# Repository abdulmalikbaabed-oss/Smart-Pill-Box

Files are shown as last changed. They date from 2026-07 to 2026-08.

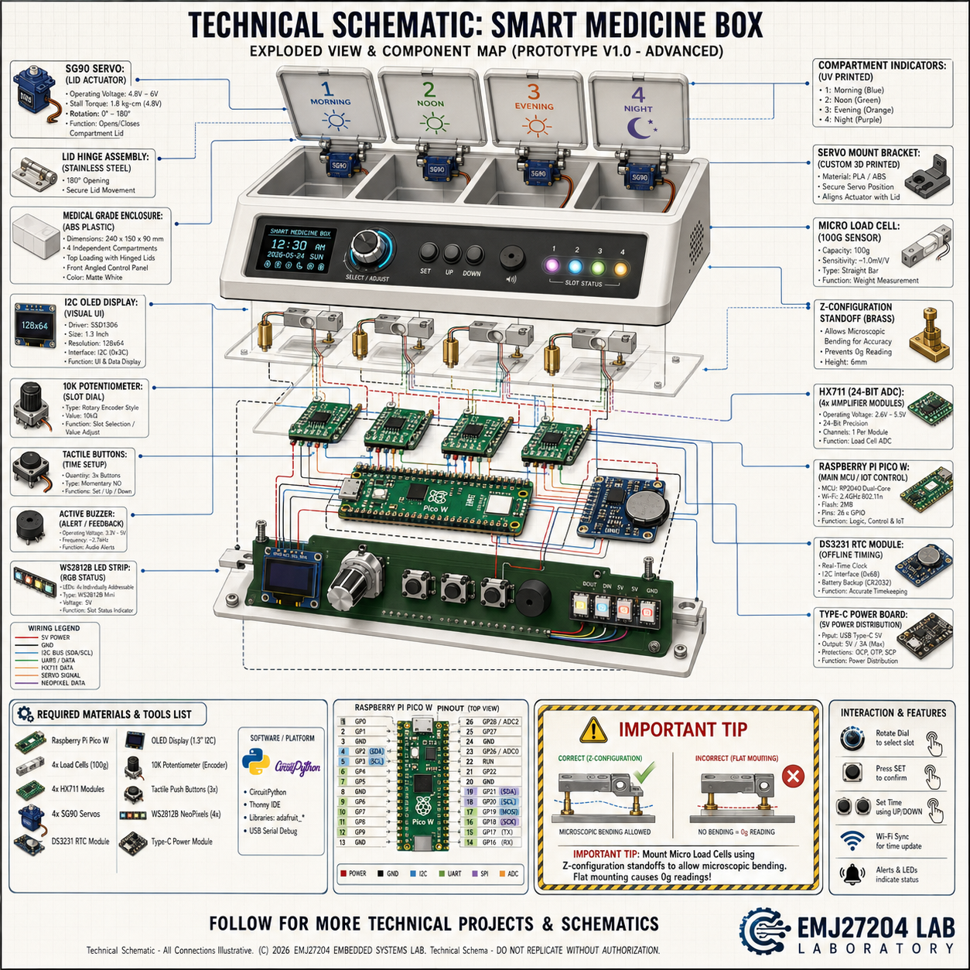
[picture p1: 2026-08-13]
04_Hardware_Schematics/Box design+3D Printing/ALBOX.png

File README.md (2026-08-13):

# 🌟 Comprehensive Operation Guide: Smart Medicine Box Project 🌟

Welcome to the "Smart Medicine Box" project. This embedded system is built on the pyRTOS architecture and object-oriented programming (OOP) using a Raspberry Pi Pico W. The system aims to monitor the elderly's adherence to their medication regimen through weight sensors, synchronize data with the cloud (Blynk IoT), and record it locally in an Excel file.

Follow these engineering steps precisely to build and run the system from scratch:

---

## 🛒 Step 1: Hardware Procurement
Before starting anything, you must ensure you have the necessary electronic components:

1. Go to the `04_Hardware_Schematics` folder and open the **Component List (Excel/PDF)** file.

2. Check the required components (e.g., Raspberry Pi Pico W, HX711, Load Cells, OLED, SG90 Servos, etc.).

3. If any components are missing, order and purchase them online or from local electronics stores before proceeding to the next steps.

---

## 💻 Step Two: Software Transfer
We will now format the system unit (Raspberry Pi Pico W):
1. Connect the Pico W board to your computer until it appears as a storage drive named `CIRCUITPY`.

2. **Transfer Libraries:** Open the `02_Libraries` folder and copy the entire `lib` folder, then paste it into the `CIRCUITPY` directory.

3. **Moving Code:** Open the `01_Source_Code` folder and copy all the Python files (`code.py`, `compartment.py`, `smart_scale.py`, `scale_config.py`, `secrets.py`) and paste them into the root directory of Pico (next to the `lib` folder).

---

## ⚙️ Step Three: Code Customization
You need to modify some data in the code to suit your network and device:

1. **Network and Cloud Settings:** - Open the **`secrets.py`** file located inside Pico.

- Change the following data as needed:

- Line 2: `"ssid": "Your Wi-Fi network name"`

- Line 3: `"password": "Your Wi-Fi password"`

- Line 4: `"blynk_token": "Your Blink token code"`

- Save the file.

2. **Connection Port Settings (for Excel Logging):**

- Open the **`logger.py`** file located in the `03_PC_Data_Logger` folder on your laptop.

- Go to **approximately line 9**: `COM_PORT = 'COM16'`

- Change `'COM16'` to the actual port number that the Pico is connecting to on your computer (you can find this using Thonny or Device Manager).

- Save the file.

---

## 🔌 Step Four: Building the Electronic Circuit (Hardware Wiring)
1. Refer to the components list (Excel) to familiarize yourself with the function of each component and its ports.

2. Open the main electronic schematic **`schematic_circuit.pdf`** located in the `04_Hardware_Schematics` folder.

3. Connect the wires precisely as shown in the schematic (ensure that the 5V power supply is separate from the 3.3V supply to avoid damaging the microcontroller).

---

## ☁️ Step Five: Setting Up the Mobile Application (Blynk IoT Setup)
To create the mobile interface and connect push notifications:

1. Open the `Blynk` folder located inside `04_Hardware_Schematics`.

2. Open the text file **`Blynk_Documentation_and_Event_Setup.txt`**.

3. This file contains a comprehensive engineering guide. Follow the instructions precisely to create Virtual Pins (V0-V15), select the appropriate widgets, and enable notification events to be sent to the patient's phone.

---

## ⚖️ Step Six: Mechanical Assembly and System Operation
1. **Physical Assembly:** Due to the sensitivity of the Load Cell, it must be mounted so that it does not touch the walls of the box. **Refer to the attached illustrations in the project archive** for the correct physical arrangement of the scale and mechanical components.

2. **Starting Data Logging:**

- Ensure that the Thunny program is completely closed to prevent it from blocking the connection.

- Navigate to the `03_PC_Data_Logger` folder.

- Open the Command Prompt (CMD) and run the code using the command: `python logger.py`

- The system will now automatically track and record each pill in the `medication_log.csv` file.

🎉 **Congratulations!** Your system is now ready and operating with high professionalism.

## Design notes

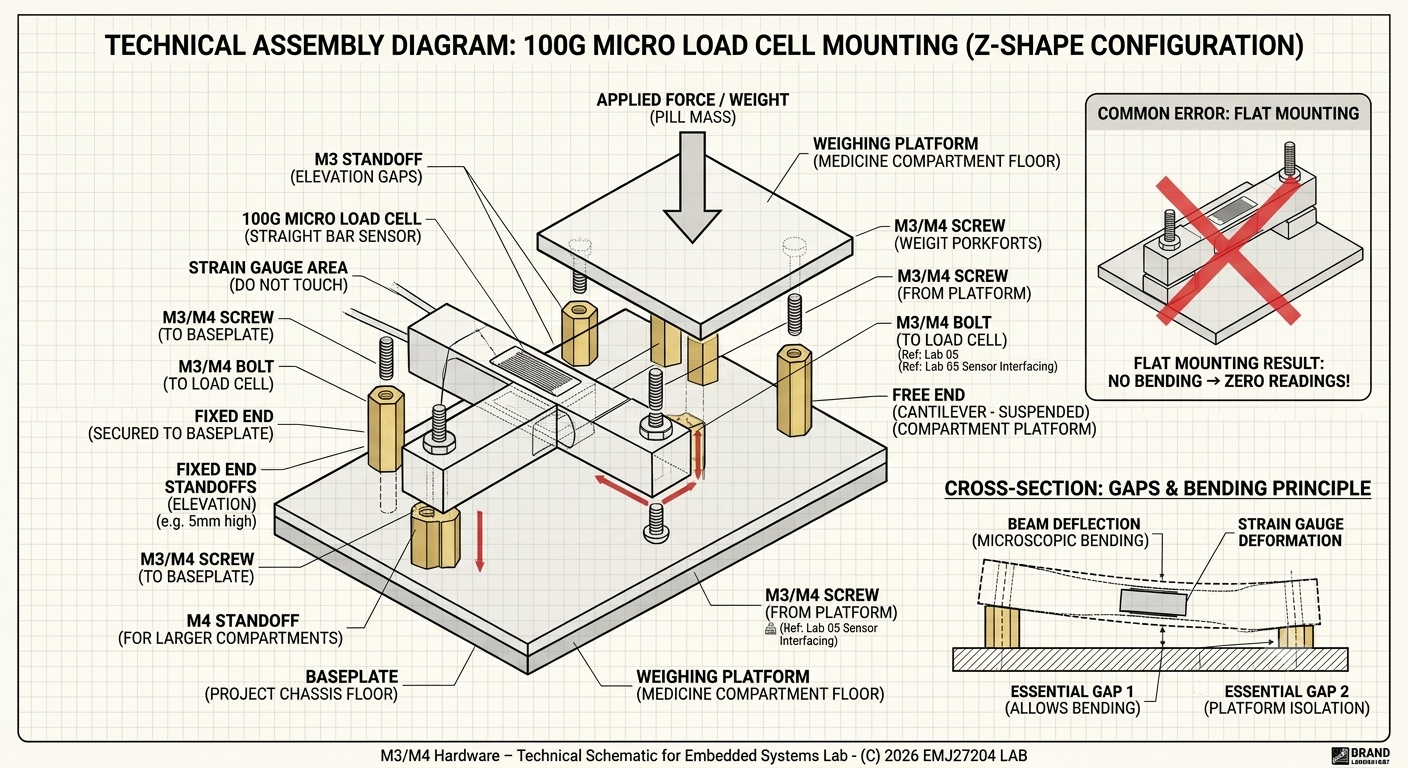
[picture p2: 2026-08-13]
04_Hardware_Schematics/LOAD CEL.png

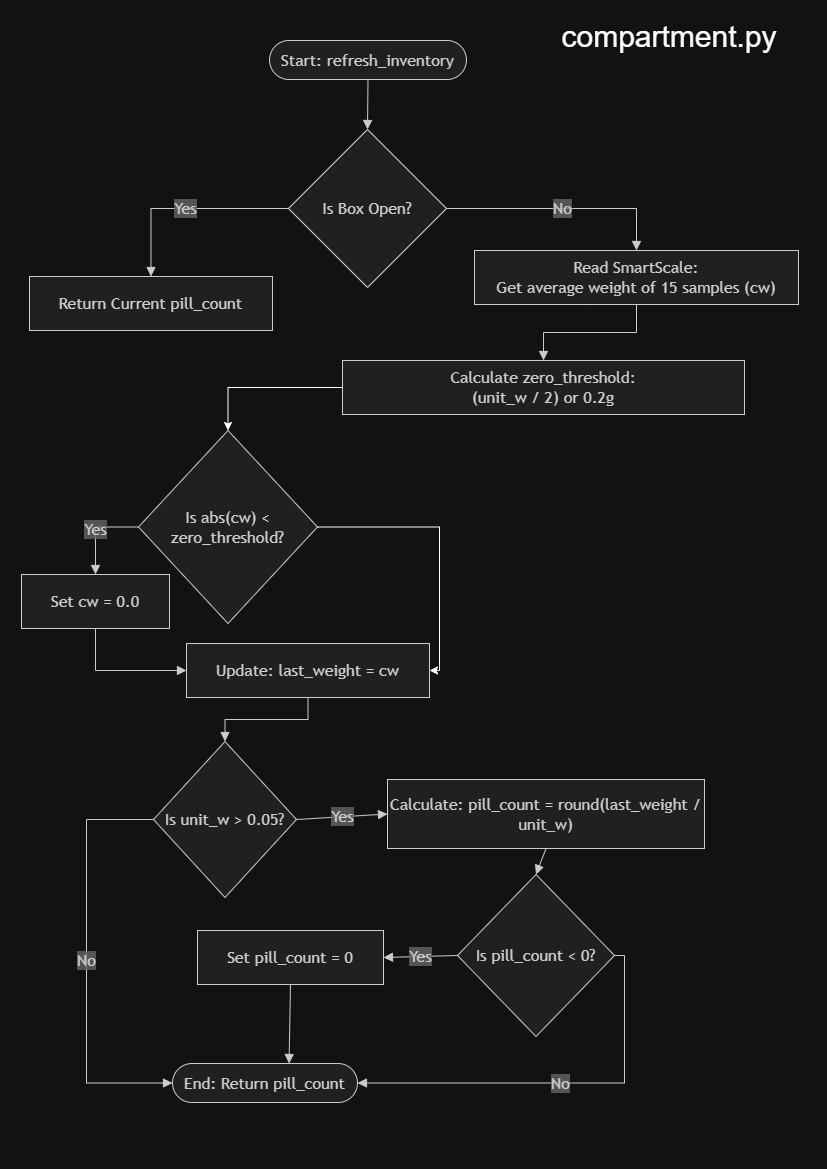
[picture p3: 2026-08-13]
01_Source_Code/flowchart/compartment.py.drawio3.png

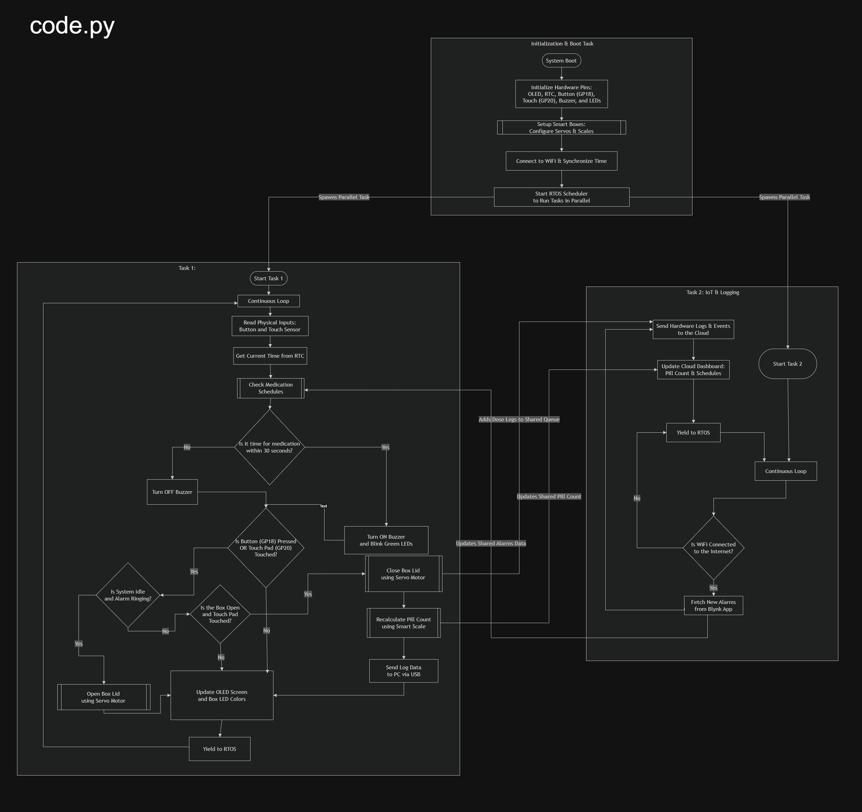
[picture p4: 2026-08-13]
01_Source_Code/flowchart/code-mine.drawio1 (1).png

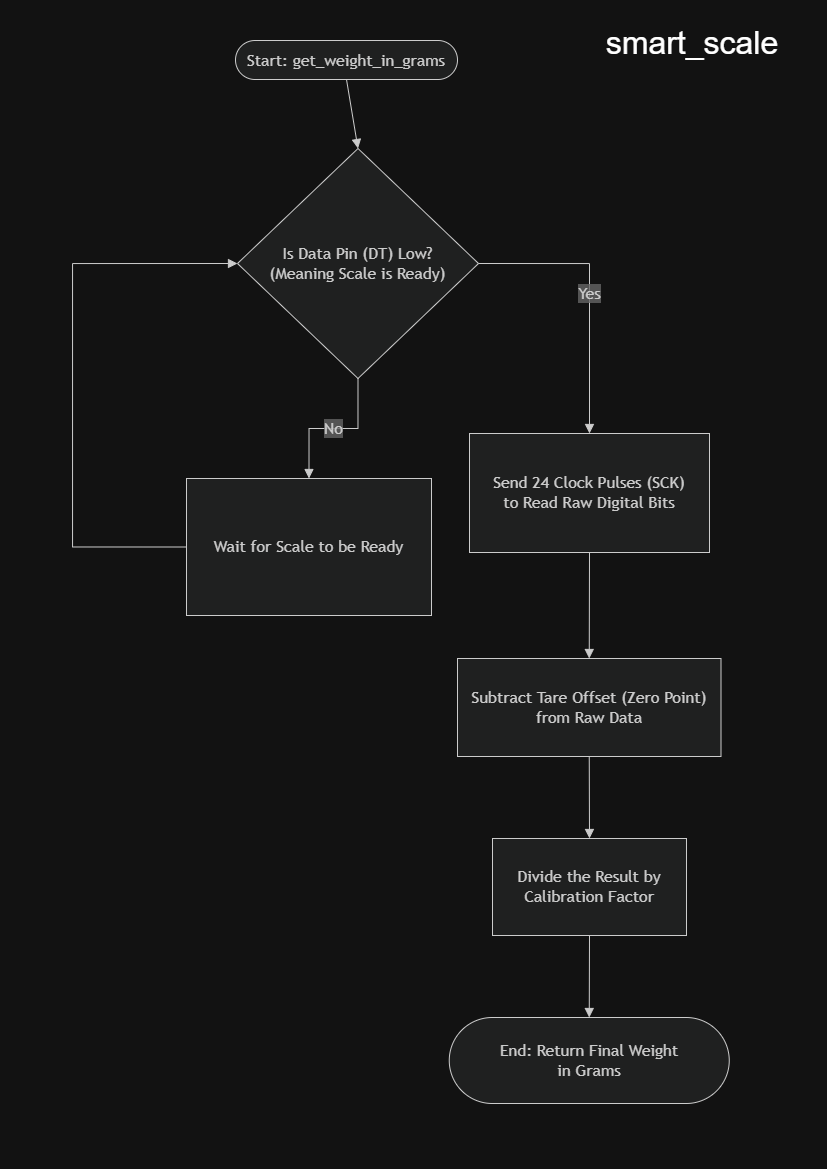
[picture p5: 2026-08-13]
01_Source_Code/flowchart/smart_scale.drawio5.png

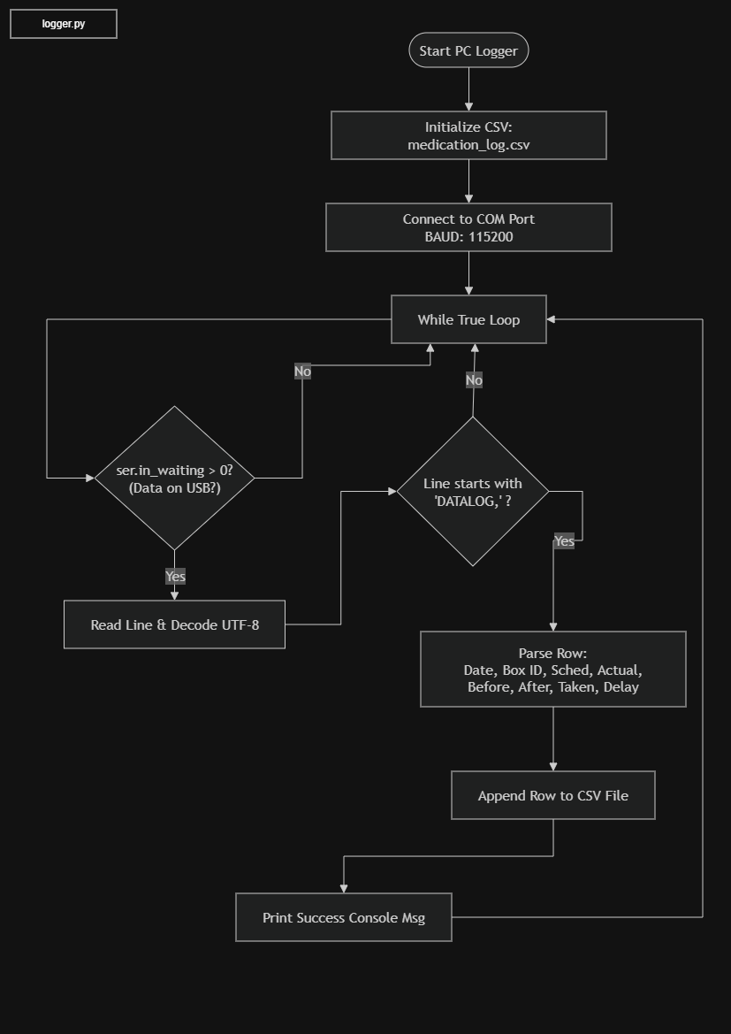
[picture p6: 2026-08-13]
01_Source_Code/flowchart/logger.drawio 2.png

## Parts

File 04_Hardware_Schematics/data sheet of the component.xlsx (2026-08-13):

NO | (Component) | Quantity | Item Price | Alternatives | Component description and function in the project
1 | Raspberry Pi Pico W | 1 | RM 45.00 | ESP32 or NodeMCU | The brain of the project, equipped with a Wi-Fi chip to connect the system to the Internet of Things (IoT).
2 | Micro Load Cell (100g or 500g) | 2 | RM 21.75 | No alternative with the same accuracy for this application. | Very accurate weight sensors (straight bar shape) placed under each slot to detect the presence or absence of a pill.
3 | HX711 Amplifier Module | 2 | RM 3.70 | None | Digital converter board (mandatory) to amplify the weak signal from the weight sensor for the controller to read.
4 | Micro Servo Motor (SG90) | 2 | RM 10.00 | DC motors with driver (consumes more power and space). | Small motors to automatically open and close the medicine slot gates (one motor per gate).
5 | I2C OLED Display | 1 | RM 5.90 | I2C LCD 16x2 Display | Small, clear screen to display the time and medicine status, its advantage is that it only uses two ports from the controller.
6 | DS3231 RTC Module | 1 | RM 6.00 | DS1307 (slightly less accurate). | Real-time clock unit to accurately save medicine times even in case of power and internet outages.
7 | CR2032 Coin Battery | 1 | RM 5.50 | - | Small coin battery placed inside the time module (RTC) to keep it running.
8 | Potentiometer (10k) | 1 | RM 0.70 | Rotary Encoder KY-040 | Variable resistor (rotary knob) will be used to navigate and select the slot number to set its time.
9 | Tactile Push Buttons | 1 | RM 1.00 | 4x4 Matrix Keypad board (consumes many ports). | Very small push buttons (button to increase, button to decrease, button to confirm and move).
10 | Capacitive Touch Sensor Module | 1 | RM 2.90
11 | WS2812B NeoPixel Strip | 1 | RM 7.43 | 4 regular RGB LEDs (consumes 12 ports from the controller). | Smart LED strip (cut 4 LEDs from it and connect them). Gives multiple colors for alerts with just one data wire.
12 | Active Buzzer (5V) | 1 | RM 1.00 | - | Active buzzer to sound an audible alarm to alert the elderly of the dose time.
13 | Type-C Breakout Board | 1 | RM 2.86 | 18650 Battery Shield V3 (if you want to run it on battery). | Small board placed on the breadboard, receives the phone charger cable and distributes a stable 5V power to run the motors.
14 | Electrolytic Capacitor (1000µF) | 1 or 2 | RM 2.60 | 470µF capacitor | Electrolytic capacitor placed in the motor power path to absorb electrical shocks and prevent system restart.
15 | Brass Standoffs (M3 or M4) | 1 (set) | RM 5.18 | Small plastic pieces you cut and glue yourself. | Small brass or plastic standoffs and screws (mandatory) to raise the weight sensors off the floor so they can bend and measure.
16 | Breadboard | 2 | RM 2.00 | Soldering components directly (not recommended before verifying the code). | Wide breadboards to assemble and connect all parts without soldering in the prototype building phase.
17 | Jumper Wires (Dupont) | 1 (set) | RM 3.00 | Regular cut copper wires. | Jumper wires bundle of three types (male-male, female-female, male-female).
18 | Box design+3D Printing | 1 | RM 35.00
 | Total | 27 | RM 161.52 | - | -
 |  |  | RM 53.84

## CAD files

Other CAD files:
04_Hardware_Schematics/Box design+3D Printing/albox.dwg
04_Hardware_Schematics/Box design+3D Printing/albox.ipt

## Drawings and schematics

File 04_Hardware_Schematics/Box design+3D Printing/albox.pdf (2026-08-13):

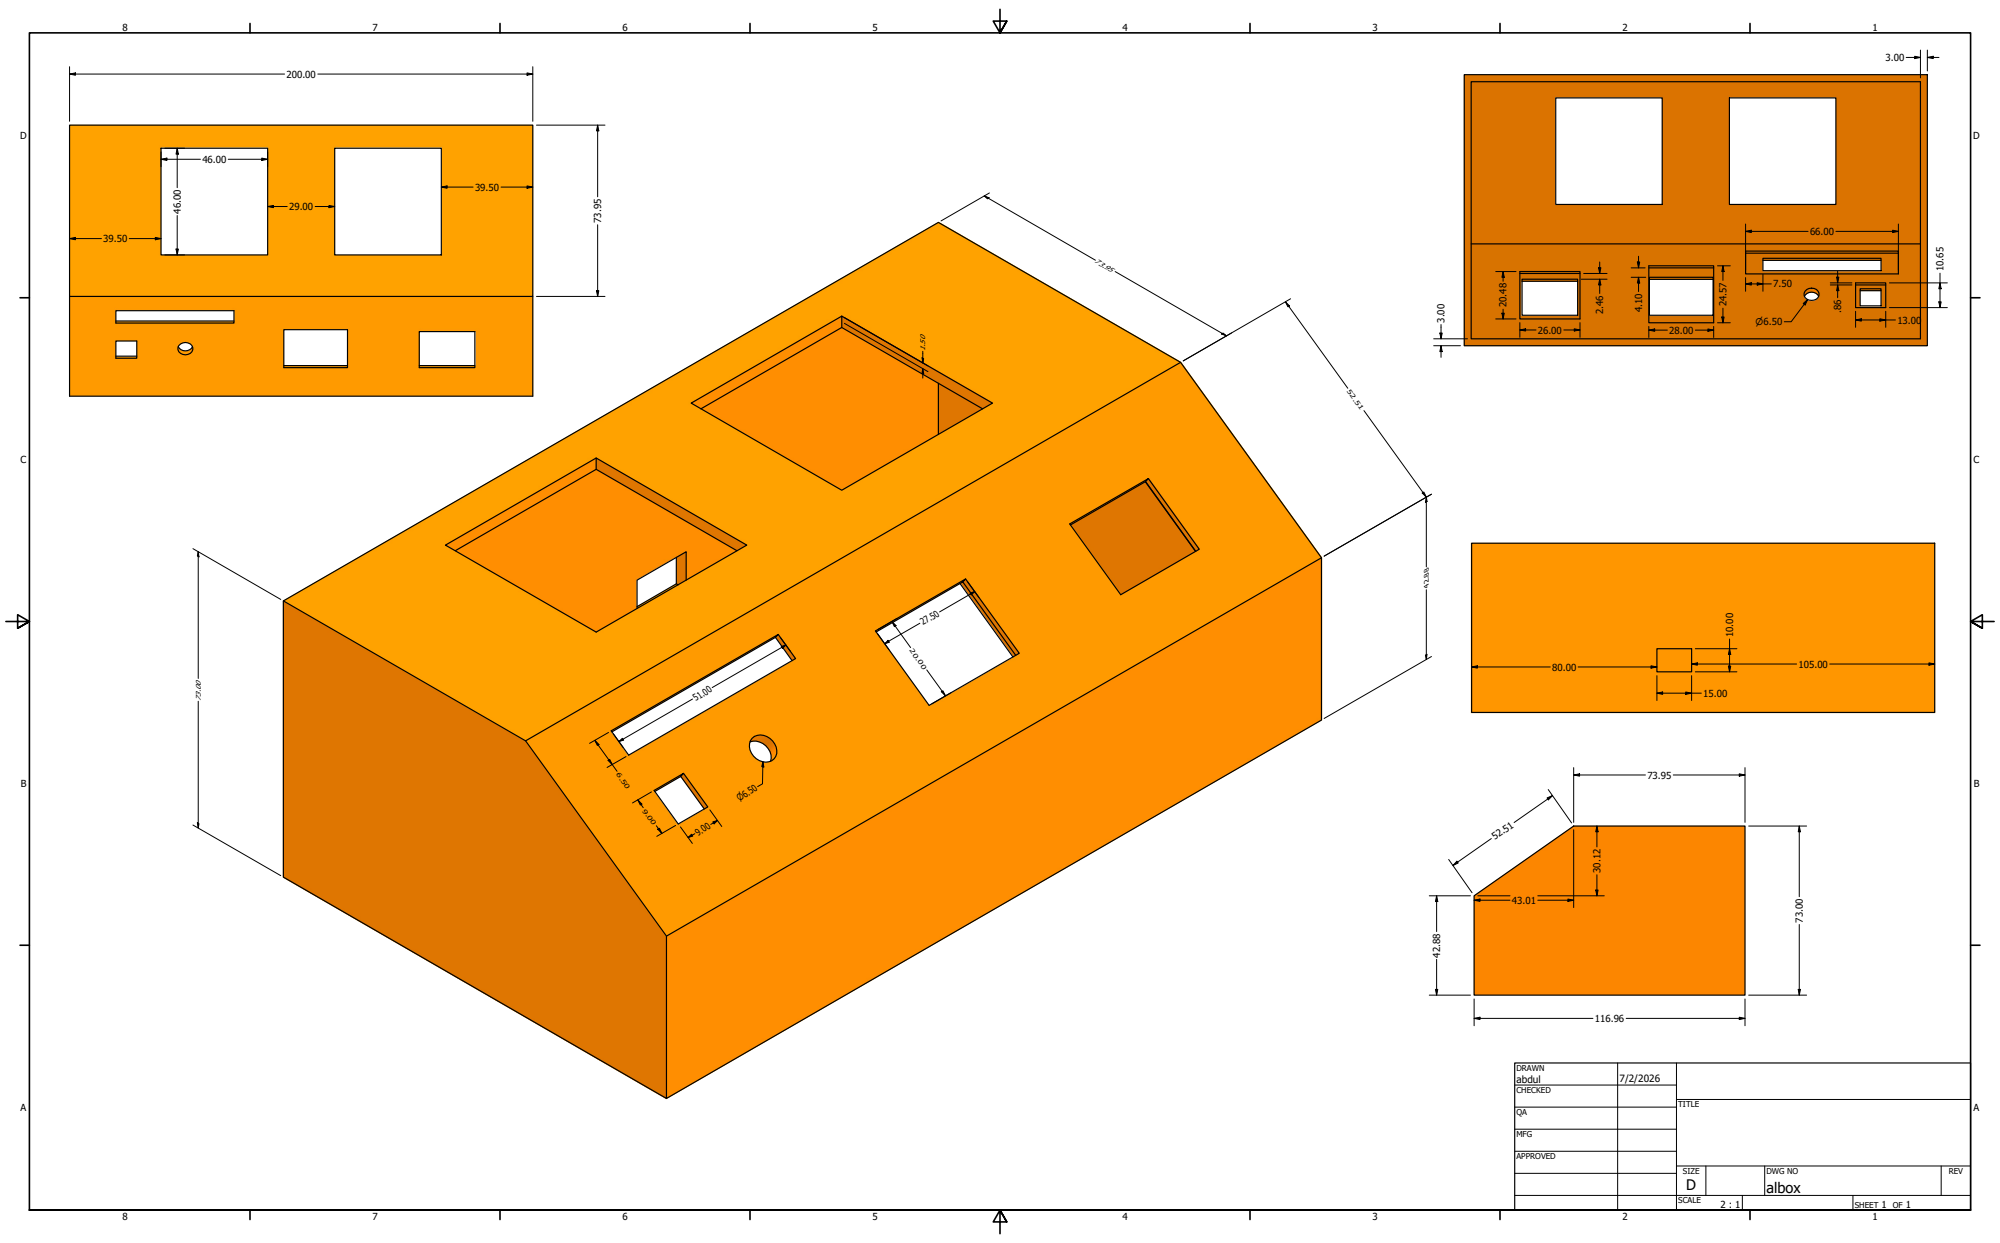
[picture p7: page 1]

S I Z E D | D W G N O alb o x | R E V

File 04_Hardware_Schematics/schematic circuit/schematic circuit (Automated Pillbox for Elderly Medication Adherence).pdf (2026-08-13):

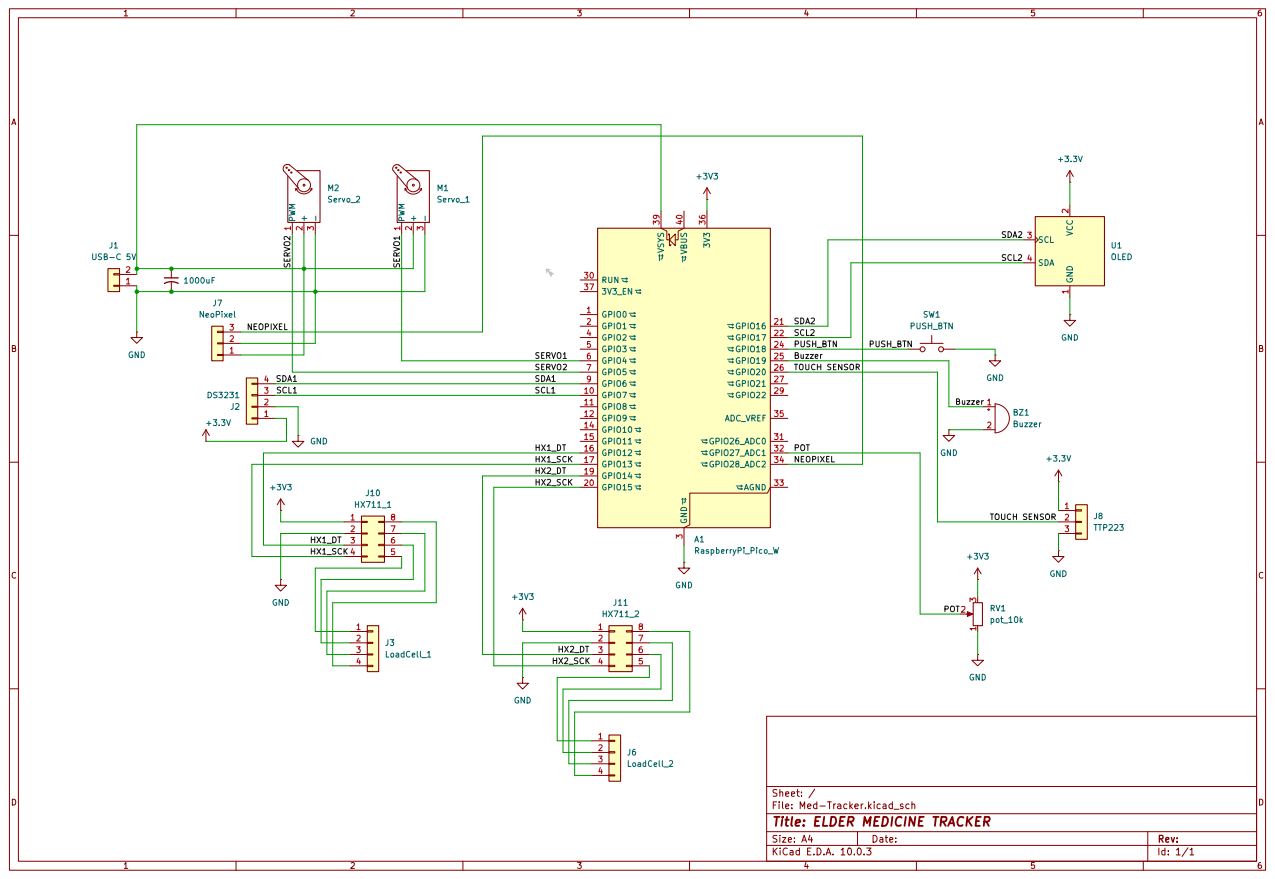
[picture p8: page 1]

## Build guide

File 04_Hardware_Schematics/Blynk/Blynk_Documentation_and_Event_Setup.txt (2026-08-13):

================================================================================
           AUTOMATED PILLBOX FOR ELDERLY MEDICATION ADHERENCE
                    BLYNK IOT CLOUD SPECIFICATIONS MAP
================================================================================

This document details the definitive Datastream configuration and hardware mapping
for the Blynk IoT cloud architecture, alongside the implementation blueprint for
the push notification event management system.

--------------------------------------------------------------------------------
1. VIRTUAL PINS & WIDGET CONFIGURATION MAP
--------------------------------------------------------------------------------

[SECTION A: COMPLIANCE MONITORING & REAL-TIME ANALYTICS]

* Virtual Pin: V15
  - Widget Type: Terminal
  - Data Type: String
  - Purpose: Medical Compliance Logbook
  - Description: Serves as the central interface for real-time edge analytics. 
    Whenever a patient safely disposes of a pill and the load cell array stabilizes, 
    the Raspberry Pi Pico W pushes a comprehensive localized report directly to this 
    terminal widget, logging the exact schedule time, actual taken time, remaining 
    pill count, and calculated delay metrics in minutes.

[SECTION B: PATIENT ADHERENCE Schedulers (READ-ONLY INTERFACE)]

* Virtual Pin: V4
  - Widget Type: Labeled Value / Value Display
  - Data Type: String
  - Label Title: "Box 1 Next Alarm"
  - Description: Displays the upcoming pre-programmed medication schedule for the 
    first medicine compartment. Computed locally by the microcontroller using edge logic.

* Virtual Pin: V5
  - Widget Type: Labeled Value / Value Display
  - Data Type: String
  - Label Title: "Box 2 Next Alarm"
  - Description: Displays the upcoming pre-programmed medication schedule for the 
    second medicine compartment.

[SECTION C: DIGITAL INVENTORY / SCALE TELEMETRY]

* Virtual Pin: V2
  - Widget Type: Labeled Value / Gauge
  - Data Type: Integer (Min: 0, Max: 20)
  - Label Title: "Box 1 Pill Count"
  - Description: Reflects the discrete pill count verified by the quantized weight 
    telemetry from the HX711 Load Cell Amplifier linked to the first compartment.

* Virtual Pin: V3
  - Widget Type: Labeled Value / Gauge
  - Data Type: Integer (Min: 0, Max: 20)
  - Label Title: "Box 2 Pill Count"
  - Description: Reflects the discrete pill count verified by the quantized weight 
    telemetry from the HX711 Load Cell Amplifier linked to the second compartment.

[SECTION D: REMOTE MEDICATION SCHEDULING (WRITE INTERFACE)]

* Virtual Pin: V8
  - Widget Type: Text Input / Time Input
  - Data Type: String
  - Placeholder: "HH:MM"
  - Description: Asynchronous write stream allowing remote clinicians or caretakers 
    to insert new medication alert boundaries for Compartment 1 directly from the cloud.

* Virtual Pin: V9
  - Widget Type: Text Input / Time Input
  - Data Type: String
  - Placeholder: "HH:MM"
  - Description: Asynchronous write stream allowing remote clinicians or caretakers 
    to insert new medication alert boundaries for Compartment 2 directly from the cloud.

--------------------------------------------------------------------------------
2. STEP-BY-STEP BLUEPRINT: BLYNK EVENT MANAGEMENT & PUSH NOTIFICATIONS
--------------------------------------------------------------------------------
To achieve full loop communication between the Raspberry Pi Pico W edge node and 
the mobile phone, follow this rigorous step-by-step procedure to define events 
and tie them to mobile device push alerts:

STEP 1: DEFINE HARDWARE EVENT TRIGGERS IN BLYNK CONSOLE
1. Navigate to the Blynk Web Console and open your Template settings.
2. Select the "Events" tab on the top horizontal options menu.
3. Click "+ Add New Event" to initialize a customized alert trigger.
4. Name the event codes exactly as specified in the PyRTOS network task:
   - Event 1 Name: "Box 1 Alarm Active" -> Set Event Code to: box_1_alarm
   - Event 2 Name: "Box 2 Alarm Active" -> Set Event Code to: box_2_alarm
5. Set the Event Type to "Critical" or "Warning" to grant it strict visual priority 
   on mobile devices.

STEP 2: ENABLE THE Cloud-to-Mobile NOTIFICATION ENGINE
1. While still inside the specific Event Configuration pane, navigate to the 
   "Notifications" sub-tab.
2. Turn ON the toggle switch labeled "Send push notifications to mobile app".
3. Set the Notification delivery target parameter to "Device Owner" or "All Users 
   with access to the device".
4. Compose the dynamic alert message body that will display on the phone screen:
   - Message for box_1_alarm: "⚠️ Critical: Medication window has arrived for Box 1! Please tap sensor to open."
   - Message for box_2_alarm: "⚠️ Critical: Medication window has arrived for Box 2! Please tap sensor to open."
5. Click "Save" and make sure to click "Save Template" at the top right to flash 
   the cloud broker configurations.

STEP 3: MOBILE INTERFACE ACTIVATION
1. Open the Blynk IoT mobile application on your iOS or Android device.
2. Enter the Template layout editor, tap on the Developer Settings gear icon, 
   and make sure that "Notifications" are globally allowed for the app within 
   your phone's Operating System settings.
3. Once the hardware invokes the explicit cloud API web hook rule via:
   "http://blynk.cloud/external/api/logEvent?token={TOKEN}&code=box_1_alarm"
   The cloud engine immediately routes the push payload to your smartphone system 
   tray instantly, ensuring absolute medical reporting stability.

================================================================================
                          END OF ARCHIVE DOCUMENT
================================================================================

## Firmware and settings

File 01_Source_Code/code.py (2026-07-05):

# File: code.py (RTOS + OOP + Fast Hardware + Serial Logging + 30s Clean Logic) Final Golden Code
import time
import board
import digitalio
import analogio
import busio
import os
import wifi
import socketpool
import adafruit_ds3231
import adafruit_ntp
import adafruit_ssd1306
import neopixel
import pyRTOS  
import adafruit_requests

from secrets import secrets
import scale_config as cfg
from compartment import MedicineCompartment

# ==========================================
# 1. Setup OLED Display and RTC Module
# ==========================================
WIDTH = 128
HEIGHT = 64
i2c_oled = busio.I2C(scl=board.GP17, sda=board.GP16)
oled = adafruit_ssd1306.SSD1306_I2C(WIDTH, HEIGHT, i2c_oled)

i2c_rtc = busio.I2C(scl=board.GP7, sda=board.GP6) 
rtc = adafruit_ds3231.DS3231(i2c_rtc)

# ==========================================
# 2. Setup Control Inputs, Buzzer, and NeoPixels
# ==========================================
potentiometer = analogio.AnalogIn(board.GP27)
button = digitalio.DigitalInOut(board.GP18)
button.direction = digitalio.Direction.INPUT
button.pull = digitalio.Pull.UP 

touch_sensor = digitalio.DigitalInOut(board.GP20)
touch_sensor.direction = digitalio.Direction.INPUT

buzzer = digitalio.DigitalInOut(board.GP19)
buzzer.direction = digitalio.Direction.OUTPUT
buzzer.value = False

pixels = neopixel.NeoPixel(board.GP28, 8, brightness=0.15, auto_write=False)

# ==========================================
# 3. Instantiate Smart Medicine Compartment Objects
# ==========================================
box1 = MedicineCompartment(
    box_id=0, servo_pin=board.GP4, angle_closed=90, angle_open=0,
    scale_dt=board.GP12, scale_sck=board.GP13, scale_factor=cfg.SCALE_2_FACTOR,
    led_indices=[4, 5, 6, 7], pixels_ref=pixels
)

box2 = MedicineCompartment(
    box_id=1, servo_pin=board.GP5, angle_closed=0, angle_open=90,
    scale_dt=board.GP14, scale_sck=board.GP15, scale_factor=cfg.SCALE_1_FACTOR,
    led_indices=[0, 1, 2, 3], pixels_ref=pixels
)

boxes = [box1, box2]

def get_pot_mapped(max_val):
    val = potentiometer.value
    mapped = (val * max_val) // 65536
    if mapped >= max_val: mapped = max_val - 1
    return mapped

def get_next_alarm_string(box, current_h, current_m, url_encoded=False):
    if not box.alarms:
        return "No%20Alarm" if url_encoded else "No Alarm"
    
    current_mins = current_h * 60 + current_m
    future_alarms = []
    all_alarms = []
    
    for a in box.alarms:
        alarm_mins = a['h'] * 60 + a['m']
        all_alarms.append((alarm_mins, a['h'], a['m']))
        if alarm_mins > current_mins:
            future_alarms.append((alarm_mins, a['h'], a['m']))
            
    if future_alarms:
        future_alarms.sort()
        next_a = future_alarms[0]
    else:
        all_alarms.sort()
        next_a = all_alarms[0]
        
    separator = "%3A" if url_encoded else ":"
    return f"{next_a[1]:02d}{separator}{next_a[2]:02d}"

# Fixed overlapping schedules issue: Buzzer triggers independently for 30s per alarm
def evaluate_box_alarm(box, current_h, current_m, current_s):
    current_mins = current_h * 60 + current_m
    untaken = [a for a in box.alarms if not a['taken']]
    
    if not untaken:
        return False, 0, None
        
    is_active = False
    min_elapsed = 9999999
    target_alarm = None

    untaken.sort(key=lambda x: x['h'] * 60 + x['m'])

    for a in untaken:
        alarm_mins = a['h'] * 60 + a['m']
        if current_mins >= alarm_mins and (current_mins - alarm_mins) < 1440:
            is_active = True
            elapsed_sec = (current_mins - alarm_mins) * 60 + current_s
            
            # Retain minimum elapsed time (most recent alarm) to trigger 30s buzzer window
            if elapsed_sec < min_elapsed:
                min_elapsed = elapsed_sec
            
            # Retain oldest untaken alarm to log accurately when patient opens the box
            if target_alarm is None:
                target_alarm = a
                
    if is_active:
        return True, min_elapsed, target_alarm
    return False, 0, None

# ==========================================
# 4. State Machine Variables
# ==========================================
sys_state = "IDLE"          
menu_action = 0             
selected_box = 0            
temp_h = 8                  
temp_m = 0                  

msg_timer = 0
measure_timer = 0
measure_count = 0
sum_w = 0.0
msg_text1 = ""
msg_text2 = ""

blynk_terminal_queue = []

# ==========================================
# 5. System Boot, WiFi Connection, and NTP Time Sync
# ==========================================
oled.fill(0); oled.text("Booting System...", 10, 15, 1)
oled.text("Auto-Taring...", 5, 35, 1); oled.show()

for box in boxes:
    box.scale.boot_tare()

pool = None 

try:
    print(">> Connecting to WiFi...")
    wifi.radio.connect(secrets["ssid"], secrets["password"])
    print(">> WiFi Connected! IP:", wifi.radio.ipv4_address)
    
    pool = socketpool.SocketPool(wifi.radio)
    
    time_synced = False
    ntp_servers = ["time.google.com", "pool.ntp.org"]
    for server_ip in ntp_servers:
        if time_synced: break 
        ntp = adafruit_ntp.NTP(pool, server=server_ip, tz_offset=8) 
        for _ in range(2): 
            try:
                rtc.datetime = ntp.datetime
                oled.fill(0); oled.text("Time Synced!", 25, 25, 1); oled.show(); time.sleep(1)
                time_synced = True
                break
            except Exception: time.sleep(1) 
except Exception as e:
    print("WiFi Error:", e)

# Removed lingering green LED: System reverts to normal state after 30 seconds
def update_running_status_leds(is_alrm1, elapsed1, is_alrm2, elapsed2, current_sec):
    for b_idx in range(2):
        group = boxes[b_idx].led_indices
        is_alrm = is_alrm1 if b_idx == 0 else is_alrm2
        elapsed = elapsed1 if b_idx == 0 else elapsed2
        
        if sys_state != "IDLE" and selected_box == b_idx and sys_state.startswith("SETUP"): continue 
        if sys_state != "IDLE" and selected_box == b_idx and sys_state.startswith("ALARM_SET"): continue

        for p in group: pixels[p] = (0, 0, 0)

        if boxes[b_idx].is_open: 
            color = (0, 255, 255)
            for p in group: pixels[p] = color
        elif is_alrm and elapsed < 30: 
            # Flashing green LED during the initial 30-second alarm window only
            color = (0, 255, 0) if (current_sec % 2 == 0) else (0, 0, 0)
            for p in group: pixels[p] = color
        elif boxes[b_idx].pill_count <= 0: 
            # Revert to solid red if time has passed and compartment is empty
            color = (255, 0, 0) 
            for p in group: pixels[p] = color
        else: 
            # Revert to normal yellow/orange if time has passed and compartment has pills
            color = (255, 180, 0) 
            for p in group: pixels[p] = color
            
    pixels.show()
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

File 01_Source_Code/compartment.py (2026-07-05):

# File: compartment.py
import time
import pwmio
from adafruit_motor import servo
from smart_scale import SmartScale

class MedicineCompartment:
    def __init__(self, box_id, servo_pin, angle_closed, angle_open, 
                 scale_dt, scale_sck, scale_factor, 
                 led_indices, pixels_ref):
        
        self.box_id = box_id
        
        # 1. Servo Motor Setup
        pwm = pwmio.PWMOut(servo_pin, duty_cycle=2 ** 15, frequency=50)
        self.servo = servo.Servo(pwm)
        self.angle_closed = angle_closed
        self.angle_open = angle_open
        self.is_open = False
        self.servo.angle = self.angle_closed 
        
        # 2. Scale Setup (SmartScale Instance)
        self.scale = SmartScale(scale_dt, scale_sck, scale_factor, name=f"Box {box_id+1}")
        self.pill_count = 0
        self.last_weight = 0.0  
        
        # 3. LED Lighting Setup
        self.led_indices = led_indices
        self.pixels = pixels_ref  
        
        # 4. Multi-Alarm Schedule Storage
        self.alarms = [] 
        
    def open_lid(self):
        self.servo.angle = self.angle_open
        self.is_open = True
        
    def close_lid(self):
        self.servo.angle = self.angle_closed
        self.is_open = False
        time.sleep(0.5) 
        
    def refresh_inventory(self):
        """Update weight telemetry and pill count using discrete mathematical quantization."""
        if not self.is_open:
            # Sample multi-reading average using verified robust method
            cw = self.scale.get_weight(samples=15)
            
            # Dynamic zero-threshold filter: Treats noise below half a pill unit weight as absolute zero
            zero_threshold = (self.scale.unit_w / 2) if self.scale.unit_w > 0.05 else 0.2
            if abs(cw) < zero_threshold: 
                cw = 0.0
                
            self.last_weight = cw
            
            # Precisely calculate discrete pill count via mathematical rounding
            if self.scale.unit_w > 0.05:
                self.pill_count = int(round(self.last_weight / self.scale.unit_w))
                if self.pill_count < 0: 
                    self.pill_count = 0
        return self.pill_count

    # ----------------------------------------
    # Multi-Alarm Schedule Methods
    # ----------------------------------------
    def add_alarm(self, hour, minute):
        self.alarms.append({"h": hour, "m": minute, "taken": False})
        
    def clear_alarms(self):
        self.alarms = []

    def is_time_for_medicine(self, current_h, current_m):
        for alarm in self.alarms:
            if alarm["h"] == current_h and alarm["m"] == current_m and not alarm["taken"]:
                return True
        return False
        
    def mark_medicine_taken(self, current_h, current_m):
        for alarm in self.alarms:
            if alarm["h"] == current_h and alarm["m"] == current_m:
                alarm["taken"] = True
                
    def reset_daily_alarms(self, current_h, current_m):
        for alarm in self.alarms:
            if current_h != alarm["h"] or current_m != alarm["m"]:
                alarm["taken"] = False

    # ----------------------------------------
    # UI & Lighting Control Methods
    # ----------------------------------------
    def set_setup_step(self, step_num):
        for idx in self.led_indices:
            self.pixels[idx] = (0, 0, 0)
        if 1 <= step_num <= len(self.led_indices):
            target_pixel = self.led_indices[step_num - 1]
            self.pixels[target_pixel] = (0, 100, 255)
        self.pixels.show()

    def set_box_solid_color(self, color):
        for idx in self.led_indices:
            self.pixels[idx] = color
        self.pixels.show()

    def update_leds(self, is_alarm_active, blink_state):
        COLOR_RED    = (255, 0, 0)
        COLOR_YELLOW = (255, 180, 0)
        COLOR_GREEN  = (0, 255, 0)
        COLOR_CYAN   = (0, 255, 255)
        COLOR_OFF    = (0, 0, 0)

        color = COLOR_OFF
        if self.is_open:
            color = COLOR_CYAN
        elif is_alarm_active:
            color = COLOR_GREEN if blink_state else COLOR_OFF
        elif self.pill_count <= 0:
            color = COLOR_RED
        else:
            color = COLOR_YELLOW
            
        for idx in self.led_indices:
            self.pixels[idx] = color
